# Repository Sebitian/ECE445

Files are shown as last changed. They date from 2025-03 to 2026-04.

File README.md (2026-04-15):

# Smart Bike Lock System (Secured Illini)

Embedded IoT system for real-time bike security, combining Bluetooth authentication, motion-based tamper detection, and cloud monitoring. Designed and built as a full-stack hardware + firmware solution with a custom PCB, power subsystem, and multi-state control architecture.

<p align="center">
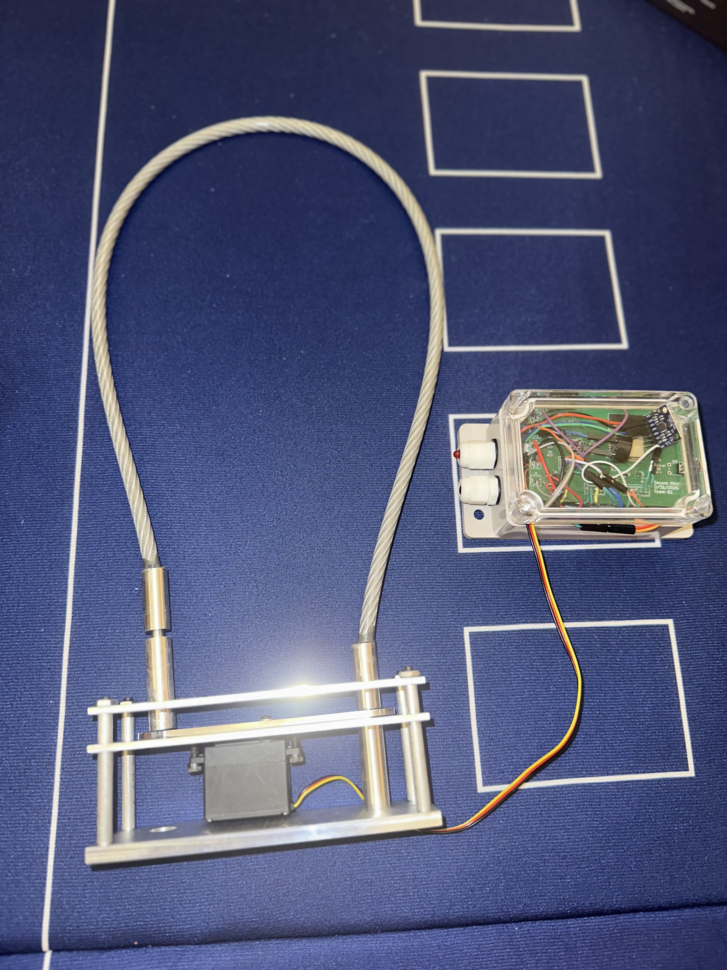
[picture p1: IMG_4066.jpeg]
Smart Bike Lock
  
</p>

---

## Overview

This project addresses the limitations of traditional bike locks by introducing a multi-layered smart security system. The device enables keyless locking via Bluetooth, detects unauthorized motion using onboard sensors, and sends real-time alerts to a cloud dashboard.

The system integrates embedded firmware, wireless communication, and physical hardware design into a single cohesive product.

---

## Key Features

- Bluetooth Low Energy (BLE) locking/unlocking
- Motion-based tamper detection using IMU (MPU6050)
- Finite State Machine (LOCKED, UNLOCKED, ALARM)
- Real-time cloud monitoring via ThingSpeak
- Servo-actuated locking mechanism
- Audible alarm + LED alert system
- Custom PCB with integrated power and control subsystems
- End-to-end system from hardware to cloud

---

## System Architecture

### Hardware
- ESP32-S3 microcontroller
- MPU6050 accelerometer/gyroscope
- Servo motor (locking mechanism)
- Piezo buzzer (alarm system)
- Custom-designed PCB
- 4.8V 2000mAh battery + 3.3V regulation (LM1117)

### Software
- Embedded C++ (Arduino framework)
- BLE server with custom services and callbacks
- HTTP-based cloud communication (ThingSpeak)
- Real-time state management using FSM

---

## Finite State Machine

The system is controlled by a 3-state FSM:

- **LOCKED**
  - Default state
  - Monitors acceleration for tampering
  - Triggers ALARM when threshold exceeded

- **UNLOCKED**
  - Triggered via authenticated BLE command
  - Disables motion-based alerts

- **ALARM**
  - Triggered on suspicious motion
  - Activates buzzer + LED flashing
  - Sends periodic cloud updates until reset

State transitions are driven by both user commands and sensor input.

---

## Motion Detection Algorithm

Tampering is detected using acceleration magnitude computed from IMU data:

- Combines x, y, z acceleration using Euclidean norm
- Adjusts for gravity (~9.8 m/s²)
- Triggers alarm when threshold exceeds ~13 m/s²

This approach enables robust detection of real-world disturbances while filtering noise.

---

## Cloud Monitoring

- Data sent via HTTP POST to ThingSpeak
- Logged data includes:
  - Lock state (LOCKED / UNLOCKED / ALARM)
  - Temperature
  - Acceleration (x, y, z)

**Performance:**
- Alert latency: ~22 seconds from tamper event to dashboard update
- Continuous updates every 15 seconds during alarm state

---

## Performance & Testing

- Lock/unlock response time: ~1.5 seconds via BLE  
- Reliable motion detection using threshold-based IMU analysis  
- Real-time alert system validated through live testing  
- Estimated battery life:
  - ~2.3 days (passive)
  - Higher under optimized conditions  

---

## Engineering Challenges

- Initial PCB revisions lacked proper USB-UART connections
- Stepper motor limitations required redesign → switched to servo
- Debugging soldering and signal integrity issues under ESP32
- BLE + WiFi integration timing and reliability

---

## Solutions

- Redesigned PCB with correct USB bridge integration
- Transitioned to servo motor for precise control
- Iterative debugging and hardware refinement
- Optimized firmware for stable communication and control

---

## Future Improvements

- Mobile application for improved user experience
- GPS tracking for stolen bike recovery
- Push notifications instead of dashboard polling
- Power optimization for extended battery life
- Modular smart attachment for existing locks

---

## Team

- Sebastian Sovailescu  
- Andrew Ruiz  
- Bowen Cui  

University of Illinois Urbana-Champaign  
ECE 445 – Senior Design

---

## Summary

This project demonstrates the design and implementation of a complete embedded system integrating hardware, firmware, and cloud infrastructure. It highlights real-world engineering challenges, iterative development, and system-level thinking in building a practical IoT security device.

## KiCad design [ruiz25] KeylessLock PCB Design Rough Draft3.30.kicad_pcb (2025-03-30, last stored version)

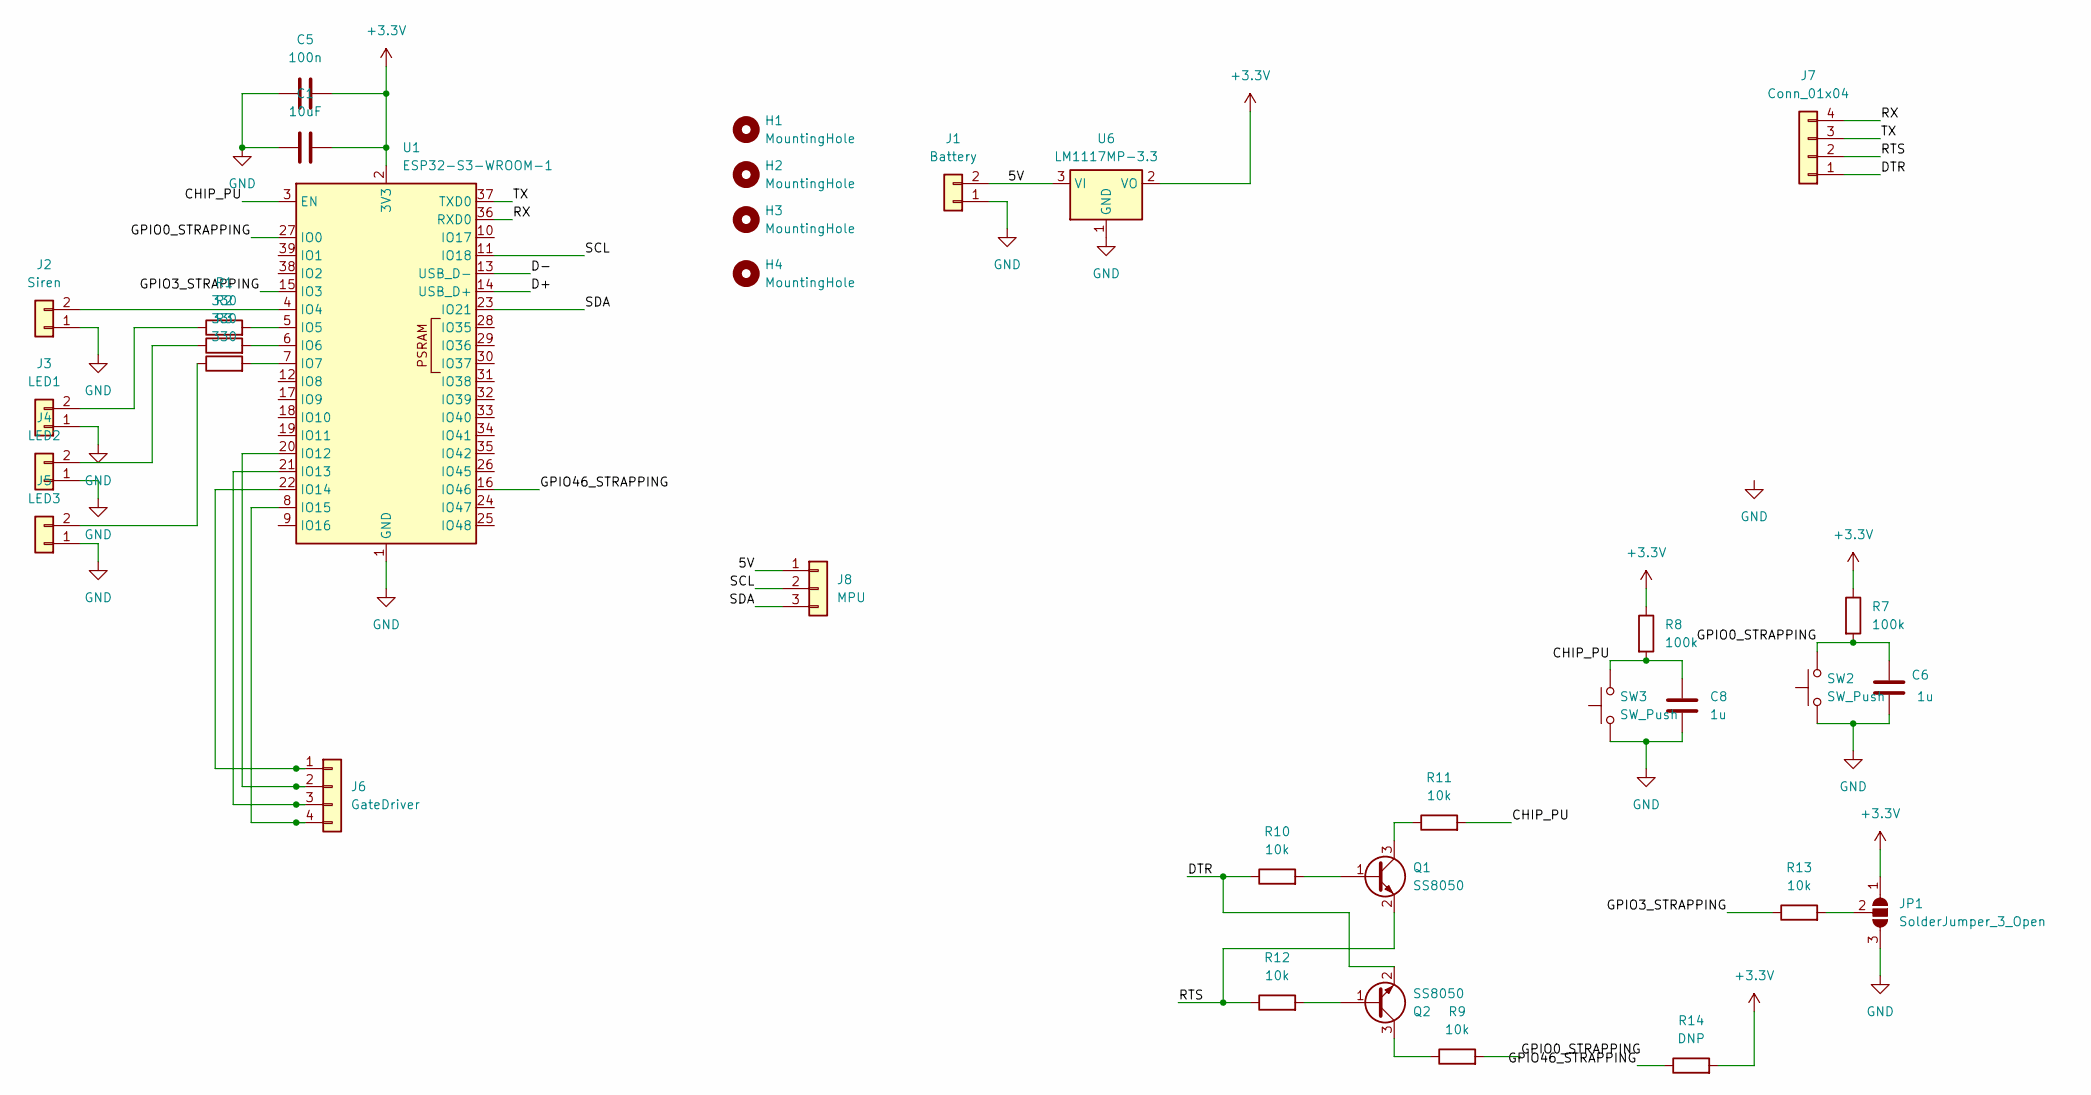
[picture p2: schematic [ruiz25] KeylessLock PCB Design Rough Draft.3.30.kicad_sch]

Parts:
C1: 10uF; C_0805_2012Metric_Pad1.18x1.45mm_HandSolder
C5: 100n; C_0805_2012Metric_Pad1.18x1.45mm_HandSolder
C6, C8: 1u; C_0805_2012Metric_Pad1.18x1.45mm_HandSolder
H1, H2, H3, H4: MountingHole; MountingHole_3.2mm_M3
J1: Battery; Molex_KK-254_AE-6410-02A_1x02_P2.54mm_Vertical
J2: Siren; Molex_KK-254_AE-6410-02A_1x02_P2.54mm_Vertical
J3: LED1; Molex_KK-254_AE-6410-02A_1x02_P2.54mm_Vertical
J4: LED2; Molex_KK-254_AE-6410-02A_1x02_P2.54mm_Vertical
J5: LED3; Molex_KK-254_AE-6410-02A_1x02_P2.54mm_Vertical
J6: GateDriver; Molex_KK-254_AE-6410-04A_1x04_P2.54mm_Vertical
J7: Conn_01x04; Molex_KK-254_AE-6410-04A_1x04_P2.54mm_Vertical
J8: MPU; Molex_KK-254_AE-6410-03A_1x03_P2.54mm_Vertical
JP1: SolderJumper_3_Open; R_0805_2012Metric_Pad1.20x1.40mm_HandSolder
Q1, Q2: SS8050; SOT-23
R1, R2, R3: 330; R_0805_2012Metric_Pad1.20x1.40mm_HandSolder
R7, R8: 100k; R_0805_2012Metric_Pad1.20x1.40mm_HandSolder
R9, R10, R11, R12, R13: 10k; R_0805_2012Metric_Pad1.20x1.40mm_HandSolder
R14: DNP; R_0805_2012Metric_Pad1.20x1.40mm_HandSolder
SW2, SW3: SW_Push; SW_PUSH_6mm
U1: ESP32-S3-WROOM-1
U6: LM1117MP-3.3; SOT-223-3_TabPin2

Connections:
+3.3V: C1.2, C5.2, JP1.1 (A), R7.1, R8.1, R14.2, U1.2 (3V3), U6.2 (VO)
/5V: J1.2, J8.1, U6.3 (VI)
/CHIP_PU: C8.1, R8.2, R11.2, SW3.2, U1.3 (EN)
/D+: U1.14 (USB_D+)
/D-: U1.13 (USB_D-)
/DTR: J7.1, Q2.2 (E), R10.1
/GPIO0_STRAPPING: C6.1, R7.2, R9.2, SW2.2, U1.27 (IO0)
/GPIO3_STRAPPING: R13.1, U1.15 (IO3)
/GPIO46_STRAPPING: R14.1, U1.16 (IO46)
/RTS: J7.2, Q1.2 (E), R12.1
/RX: J7.4, U1.36 (RXD0)
/SCL: J8.2, U1.11 (IO18)
/SDA: J8.3, U1.23 (IO21)
/TX: J7.3, U1.37 (TXD0)
GND: C1.1, C5.1, C6.2, C8.2, J1.1, J2.1, J3.1, J4.1, J5.1, JP1.3 (B), SW2.1, SW3.1, U1.1 (GND), U1.40 (GND), U1.41 (GND), U6.1 (GND)
unnamed: J2.2, U1.4 (IO4)
unnamed: J3.2, R1.1
unnamed: J4.2, R2.1
unnamed: J5.2, R3.1
unnamed: J6.1, U1.22 (IO14)
unnamed: J6.2, U1.20 (IO12)
unnamed: J6.3, U1.21 (IO13)
unnamed: J6.4, U1.8 (IO15)
unnamed: JP1.2 (C), R13.2
unnamed: Q1.1 (B), R10.2
unnamed: Q1.3 (C), R11.1
unnamed: Q2.1 (B), R12.2
unnamed: Q2.3 (C), R9.1
unnamed: R1.2, U1.5 (IO5)
unnamed: R2.2, U1.6 (IO6)
unnamed: R3.2, U1.7 (IO7)

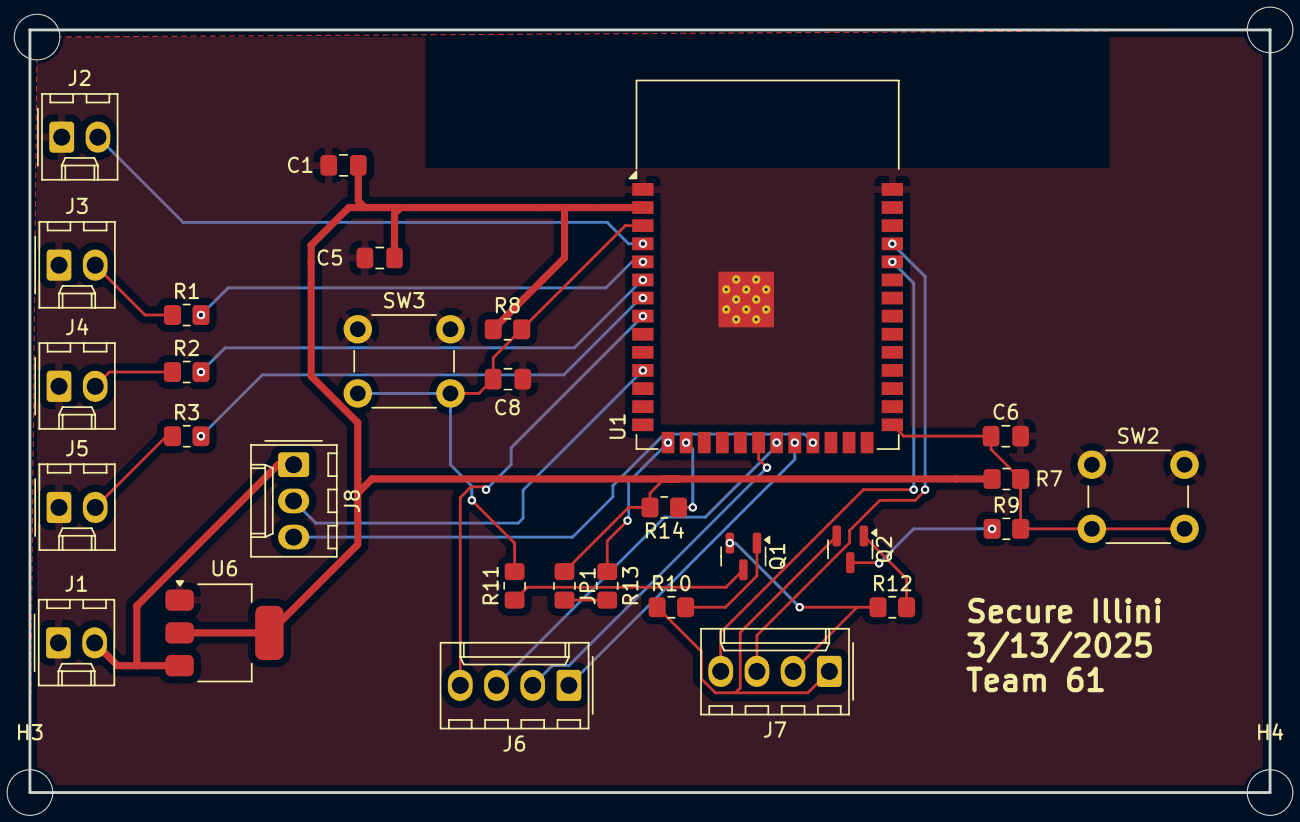
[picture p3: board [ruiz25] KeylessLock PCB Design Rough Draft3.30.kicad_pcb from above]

Board: 2 copper layers, 87.0 x 53.5 mm, 34 parts (0 on the bottom side), 29 nets.

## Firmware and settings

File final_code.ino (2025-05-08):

#include <ESP32Servo.h>
#include <Arduino.h>
#include <BLEDevice.h>
#include <BLEServer.h>
#include <BLEUtils.h>
#include <BLE2902.h>
#include <WiFi.h>
#include "ThingSpeak.h"
#include <math.h>
#include <HTTPClient.h>
#include <Adafruit_MPU6050.h>
#include <Adafruit_Sensor.h>
#include <Wire.h>
#include "pitches.h"

#define LED_PIN   7
#define SERVO_PIN 14
#define SDA_PIN     21   // your SDA pin
#define SCL_PIN     18   // your SCL pin
#define NOTE_E5  659
#define BUZZER_PIN  4

// FSM
enum LockState { LOCKED, UNLOCKED, ALARM };
LockState currentState = LOCKED;
LockState previousState = LOCKED; // Track previous state to detect changes
const float IMU_THRESHOLD = 13.0;

// MPU6050
Adafruit_MPU6050 mpu;
float temperatureC;

//==== WIFI ====
// const char* ssid       = "YOUR_SSID";       // Replace with your WiFi name
// const char* password   = "YOUR_PASSWORD";   // Replace with your WiFi password
const char* ssid       = "YOUR_WIFI_SSID";
const char* password   = "YOUR_WIFI_PASSWORD";

// === THINGSPEAK =============================================
unsigned long myChannelNumber = 1;
const char*    myWriteAPIKey  = "YOUR_THINGSPEAK_API_KEY";
const char*    serverName     = "http://api.thingspeak.com/update";

// SERVO 
Servo myservo;

// BLE ===============================================
// BLE Server callbacks (connection state)

// COMMANDS
void reset_alarm(); // type 'reset'
void play_rickroll(); // type 'rick'
void play_got_theme(); // type 'got'
void play_melody(); 
void send_to_thinkspeak();

static bool deviceConnected = false;

class ServerCallbacks : public BLEServerCallbacks {
  void onConnect(BLEServer* pServer)   override { deviceConnected = true; }
  void onDisconnect(BLEServer* pServer)override { 
    deviceConnected = false; 
    pServer->startAdvertising(); 
  }
};

// BLE Characteristic write handler
class CharCallbacks : public BLECharacteristicCallbacks {
  void onWrite(BLECharacteristic* pChar) override {
    String rx = pChar->getValue();
    if (rx.equals("open")) {
      digitalWrite(LED_PIN, HIGH);
      myservo.attach(SERVO_PIN, 1000, 2000);
      for (int pos = 0; pos <= 180; pos += 2) {
        myservo.write(pos);
        delay(15);
      }
      myservo.detach();
      
      // Change state to UNLOCKED when opening via Bluetooth
      if (currentState != UNLOCKED) {
        previousState = currentState;
        currentState = UNLOCKED;
        // Send state change to ThingSpeak
        send_to_thinkspeak();
        Serial.println("STATE: Changed to UNLOCKED");
      }
    }
    else if (rx.equals("close")) {
      digitalWrite(LED_PIN, LOW);
      myservo.attach(SERVO_PIN, 1000, 2000);
      for (int pos = 180; pos >= 0; pos -= 2) {
        myservo.write(pos);
        delay(15);
      }
      myservo.detach();
      
      // Change state to LOCKED when closing via Bluetooth
      if (currentState != LOCKED) {
        previousState = currentState;
        currentState = LOCKED;
        // Send state change to ThingSpeak
        send_to_thinkspeak();
        Serial.println("STATE: Changed to LOCKED");
      }
    }
    else if (rx.equals("reset")) {
      // Reset the alarm state via Bluetooth
      reset_alarm();
    }
    else if (rx.equals("rick")) {
      // Play the Rick Roll melody when receiving "rick" command
      Serial.println("Rick Roll activated!");
      play_rickroll();
    }
    else if (rx.equals("got")) {
      // Play the Game of Thrones theme when receiving "got" command
      Serial.println("Game of Thrones theme activated!");
      play_got_theme();
    }
  }
};


//==== BUZZER ====
int melody[]       = { NOTE_E5, NOTE_E5, NOTE_E5 };
int noteDurations[] = { 8, 8, 4 };

// WIFI
void init_WiFi() {
  WiFi.mode(WIFI_STA);
  WiFi.begin(ssid, password);
  while (WiFi.status() != WL_CONNECTED) {
    Serial.print('.');
    digitalWrite(LED_PIN, HIGH);
    delay(300);
    digitalWrite(LED_PIN, LOW);
    delay(700);
  }
  // WiFi connected - solid LED for 3 seconds
  digitalWrite(LED_PIN, HIGH);
  delay(3000);
  digitalWrite(LED_PIN, LOW);
}

// MELODY
void play_melody() {
  // Calculate the actual number of notes in the active melody
  int size = sizeof(melody) / sizeof(int);

  for (int thisNote = 0; thisNote < size; thisNote++) {
    // Calculate note duration
    int noteDuration = 1000 / noteDurations[thisNote];
    tone(BUZZER_PIN, melody[thisNote], noteDuration);

    // Pause between notes
    int pauseBetweenNotes = noteDuration * 1.30;
    delay(pauseBetweenNotes);
    
    // Stop the tone
    noTone(BUZZER_PIN);
  }
}

// LED
void init_led() {
  pinMode(LED_PIN, OUTPUT);
  digitalWrite(LED_PIN, LOW);
}

// BLE
void init_ble() {
  
  // Prepare PWM timers (don't attach yet)
  ESP32PWM::allocateTimer(0);
  ESP32PWM::allocateTimer(1);
  ESP32PWM::allocateTimer(2);
  ESP32PWM::allocateTimer(3);

  // BLE setup
  BLEDevice::init("ESP32-S3");
  BLEServer* pServer = BLEDevice::createServer();
  pServer->setCallbacks(new ServerCallbacks());

  BLEService* pService = pServer->createService("12345678-1234-1234-1234-1234567890ab");
  BLECharacteristic* pChar = pService->createCharacteristic(
    "abcdefab-1234-1234-1234-abcdefabcdef",
    BLECharacteristic::PROPERTY_READ   |
    BLECharacteristic::PROPERTY_WRITE  |
    BLECharacteristic::PROPERTY_NOTIFY
  );
  pChar->addDescriptor(new BLE2902());
  pChar->setValue("Ready");
  pChar->setCallbacks(new CharCallbacks());

  pService->start();
  BLEDevice::getAdvertising()->addServiceUUID(pService->getUUID());
  BLEDevice::getAdvertising()->start();
}


void init_MPU6050() {
  Wire.begin(SDA_PIN, SCL_PIN);
  while (!mpu.begin()) {
    Serial.println("Failed to find MPU6050 chip");
    // MPU failure pattern: very fast blinking (10 times)
    for (int i = 0; i < 10; i++) {
      digitalWrite(LED_PIN, HIGH);
      delay(50);
      digitalWrite(LED_PIN, LOW);
      delay(50);
    }
    delay(1000);
  }
  
  // MPU found - indicate with a double blink pattern
  for (int i = 0; i < 2; i++) {
    digitalWrite(LED_PIN, HIGH);
    delay(500);
    digitalWrite(LED_PIN, LOW);
    delay(500);
  }
  
  Serial.println("MPU6050 Found!");

  mpu.setAccelerometerRange(MPU6050_RANGE_8_G);
  Serial.print("Accelerometer range set to: ");
  switch (mpu.getAccelerometerRange()) {
    case MPU6050_RANGE_2_G:
      Serial.println("+-2G");
      break;
    case MPU6050_RANGE_4_G:
      Serial.println("+-4G");
      break;
    case MPU6050_RANGE_8_G:
      Serial.println("+-8G");
      break;
    case MPU6050_RANGE_16_G:
      Serial.println("+-16G");
      break;
  }
  mpu.setGyroRange(MPU6050_RANGE_500_DEG);
  Serial.print("Gyro range set to: ");
  switch (mpu.getGyroRange()) {
    case MPU6050_RANGE_250_DEG:
      Serial.println("+- 250 deg/s");
      break;
    case MPU6050_RANGE_500_DEG:
      Serial.println("+- 500 deg/s");
      break;
    case MPU6050_RANGE_1000_DEG:
      Serial.println("+- 1000 deg/s");
      break;
    case MPU6050_RANGE_2000_DEG:
      Serial.println("+- 2000 deg/s");
      break;
  }

  mpu.setFilterBandwidth(MPU6050_BAND_5_HZ);
  Serial.print("Filter bandwidth set to: ");
  switch (mpu.getFilterBandwidth()) {
    case MPU6050_BAND_260_HZ:
      Serial.println("260 Hz");
      break;
    case MPU6050_BAND_184_HZ:
      Serial.println("184 Hz");
      break;
    case MPU6050_BAND_94_HZ:
      Serial.println("94 Hz");
      break;
    case MPU6050_BAND_44_HZ:
      Serial.println("44 Hz");
      break;
    case MPU6050_BAND_21_HZ:
      Serial.println("21 Hz");
      break;
    case MPU6050_BAND_10_HZ:
      Serial.println("10 Hz");
      break;
    case MPU6050_BAND_5_HZ:
      Serial.println("5 Hz");
      break;
  }
}

// THINGSPEAK
void send_to_thinkspeak() {
  // Short blink to indicate HTTP request is starting
  digitalWrite(LED_PIN, HIGH);
  delay(200);
  digitalWrite(LED_PIN, LOW);

  WiFiClient client;
  HTTPClient http;
  http.begin(client, serverName);
  http.addHeader("Content-type", "application/x-www-form-urlencoded");
      
  // Get sensor readings
  sensors_event_t a, g, temp;
  mpu.getEvent(&a, &g, &temp);

  // Apply temperature calibration offset (MPU6050 needs calibration)
  temperatureC = temp.temperature;  // Apply offset correction
  
  // Set the status field based on the current state
  int statusValue;
  switch (currentState) {
    case LOCKED:
      statusValue = 1;  // LOCKED state = 1
      break;
    case UNLOCKED:
      statusValue = 0;  // UNLOCKED state = 0
      break;
    case ALARM:
      statusValue = 2;  // ALARM state = 2
      break;
    default:
      statusValue = 3;  // Unknown state = 3 (should never happen)
      break;
  }

  // Get acceleration data
  float accel_x = a.acceleration.x;
  float accel_y = a.acceleration.y;
  float accel_z = a.acceleration.z;

  // Blink LED once if data is read successfully
  digitalWrite(LED_PIN, HIGH);
  delay(50);
  digitalWrite(LED_PIN, LOW);

  String httpRequestData = String("api_key=") + myWriteAPIKey +
                                "&field1=" + String(temperatureC, 2) +  // 2 decimal places precision
                              "&field2=" + statusValue +              // State indicator (1=LOCKED, 0=UNLOCKED, 2=ALARM)
                              "&field3=" + String(accel_x, 3) +       // x-axis acceleration
                              "&field4=" + String(accel_y, 3) +       // y-axis acceleration
                              "&field5=" + String(accel_z, 3);        // z-axis acceleration

  int httpResponseCode = http.POST(httpRequestData);
  
  // Indicate HTTP response status through LED
  if (httpResponseCode > 0) {
    // Success - LED stays on for 1 second
    digitalWrite(LED_PIN, HIGH);
    delay(1000);
    digitalWrite(LED_PIN, LOW);
  } else {
    // Error - Blink quickly 5 times
    for (int i = 0; i < 5; i++) {
      digitalWrite(LED_PIN, HIGH);
      delay(100);
      digitalWrite(LED_PIN, LOW);
      delay(100);
    }
  }
  
  http.end();
}

void update_lock_state() {
  // Get sensor data
  sensors_event_t a, g, temp;
  mpu.getEvent(&a, &g, &temp);

  // Calculate acceleration magnitude
  float accelerationMagnitude = sqrt(a.acceleration.x * a.acceleration.x + 
                                     a.acceleration.y * a.acceleration.y + 
                                     a.acceleration.z * a.acceleration.z);
  
  // Account for gravity (approx 9.8 m/s²)
  accelerationMagnitude = abs(accelerationMagnitude - 9.8);
  
  // Save previous state before any changes
  previousState = currentState;
  
  // Check state transitions
  switch (currentState) {
    case LOCKED:
      // If in LOCKED state and acceleration exceeds threshold, trigger ALARM
      if (accelerationMagnitude > IMU_THRESHOLD) {
        currentState = ALARM;
        Serial.println("STATE: LOCKED -> ALARM (Motion detected!)");
        
        // Send alert to ThingSpeak when state changes to ALARM
        send_to_thinkspeak();
      }
      break;
      
    case UNLOCKED:
      // In UNLOCKED state, we don't trigger alarm on motion
      // But we could add other transitions here if needed
      break;
      
    case ALARM:
      // Periodic ThingSpeak updates while in ALARM state
      static unsigned long lastThingSpeakUpdate = 0;
      unsigned long now = millis();
      
      // Send update every 15 seconds while in ALARM state
      if (now - lastThingSpeakUpdate >= 15000) {
        send_to_thinkspeak();
        lastThingSpeakUpdate = now;
        Serial.println("Sending periodic alarm update to ThingSpeak");
      }
      break;
  }
  
  // Always send update to ThingSpeak if state changed
  if (currentState != previousState) {
    // Send update to ThingSpeak for any state change
    // (we already sent for LOCKED->ALARM above, but ThingSpeak has rate limits so it's okay)
    send_to_thinkspeak();
    Serial.print("STATE: Changed from ");
    Serial.print(stateToString(previousState));
    Serial.print(" to ");
    Serial.println(stateToString(currentState));
  }
}

// Helper function to convert state enum to string for debugging
String stateToString(LockState state) {
  switch (state) {
    case LOCKED: return "LOCKED";
    case UNLOCKED: return "UNLOCKED";
    case ALARM: return "ALARM";
    default: return "UNKNOWN";
  }
}

// Handle actions based on current state
void handle_state_actions() {
  static unsigned long lastToggle = 0;
  static bool ledState = false;
  static unsigned long alarmStartTime = 0;
  
  switch (currentState) {
    case LOCKED:
      // In locked state, LED stays off
      digitalWrite(LED_PIN, LOW);
      // Reset alarm variables when returning to LOCKED state
      alarmStartTime = 0; // Reset the alarm start time so it will work again when triggered
      break;
      
    case UNLOCKED:
      // In unlocked state, LED stays on
      digitalWrite(LED_PIN, HIGH);
      // Reset alarm variables
      alarmStartTime = 0;
      break;
      
    case ALARM:
      // If this is the first time in ALARM state, record the start time
      if (alarmStartTime == 0) {
        alarmStartTime = millis();
        // Initial alert: LED on and play sound immediately
        digitalWrite(LED_PIN, HIGH);
        play_melody();
        ledState = true;
        lastToggle = millis();
      }
      
      // Continue flashing LED regardless of time spent in ALARM state
      unsigned long now = millis();
      if (now - lastToggle > 500) {
        // Toggle LED state
        ledState = !ledState;
        digitalWrite(LED_PIN, ledState);
        lastToggle = now;
        
        // Only play melody when LED turns ON and within first 10 seconds
        if (ledState && (now - alarmStartTime < 10000)) {
          play_melody(); // Play sound when LED turns on
        }
      }
      break;
  }
}

// Modified function to reset the alarm state via BLE
void reset_alarm() {
  LockState oldState = currentState;
  currentState = LOCKED;
  digitalWrite(LED_PIN, LOW);
  
  // Close the servo to ensure it's in locked position
  myservo.attach(SERVO_PIN, 1000, 2000);
  for (int pos = 180; pos >= 0; pos -= 2) {
    myservo.write(pos);
    delay(15);
  }
  myservo.detach();
  
  // Always send update to ThingSpeak when resetting alarm state
  Serial.println("STATE: Reset to LOCKED from " + stateToString(oldState));
  send_to_thinkspeak();  // Ensure ThingSpeak is updated regardless of previous state
}

// Add the Rick Roll melody notes and durations
// This is a simplified version of the melody using notes from pitches.h
void play_rickroll() {
  // Notes for "Never Gonna Give You Up" intro/chorus (simplified)
  int rickNotes[] = {
    NOTE_D5, NOTE_E5, NOTE_A4, NOTE_E5, NOTE_FS5, NOTE_A5, NOTE_G5, NOTE_FS5,
    NOTE_D5, NOTE_E5, NOTE_A4, NOTE_A4, NOTE_FS5, NOTE_G5, NOTE_E5
  };
  
  // Note durations: 4 = quarter note, 8 = eighth note, etc.
  int rickDurations[] = {
    8, 8, 8, 8, 8, 8, 8, 8,
    8, 8, 4, 8, 8, 8, 4
  };
  
  // Play each note in the melody
  for (int thisNote = 0; thisNote < sizeof(rickNotes) / sizeof(int); thisNote++) {
    // Calculate note duration
    int noteDuration = 1000 / rickDurations[thisNote];
    tone(BUZZER_PIN, rickNotes[thisNote], noteDuration);
    
    // Pause between notes (30% extra seems to sound good)
    int pauseBetweenNotes = noteDuration * 1.30;
    delay(pauseBetweenNotes);
    
    // Stop the tone
    noTone(BUZZER_PIN);
  }
}

// Add Game of Thrones theme song
#define REST 0  // Add REST note definition to play pauses

void play_got_theme() {
  // Game of Thrones theme song
  int got_melody[] = {
    NOTE_G4, NOTE_C4, NOTE_DS4, NOTE_F4, NOTE_G4, NOTE_C4, NOTE_DS4, NOTE_F4,
    NOTE_G4, NOTE_C4, NOTE_DS4, NOTE_F4, NOTE_G4, NOTE_C4, NOTE_DS4, NOTE_F4,
    NOTE_G4, NOTE_C4, NOTE_E4, NOTE_F4, NOTE_G4, NOTE_C4, NOTE_E4, NOTE_F4,
    NOTE_G4, NOTE_C4, NOTE_E4, NOTE_F4, NOTE_G4, NOTE_C4, NOTE_E4, NOTE_F4,
    NOTE_G4, NOTE_C4,
    
    NOTE_DS4, NOTE_F4, NOTE_G4, NOTE_C4, NOTE_DS4, NOTE_F4,
    NOTE_D4,
    NOTE_F4, NOTE_AS3,
    NOTE_DS4, NOTE_D4, NOTE_F4, NOTE_AS3,
    NOTE_DS4, NOTE_D4, NOTE_C4,
    
    NOTE_G4, NOTE_C4,
    
    NOTE_DS4, NOTE_F4, NOTE_G4, NOTE_C4, NOTE_DS4, NOTE_F4,
    NOTE_D4,
    NOTE_F4, NOTE_AS3,
    NOTE_DS4, NOTE_D4, NOTE_F4, NOTE_AS3,
    NOTE_DS4, NOTE_D4, NOTE_C4,
    NOTE_G4, NOTE_C4,
    NOTE_DS4, NOTE_F4, NOTE_G4, NOTE_C4, NOTE_DS4, NOTE_F4,
    
    NOTE_D4,
    NOTE_F4, NOTE_AS3,
    NOTE_D4, NOTE_DS4, NOTE_D4, NOTE_AS3,
    NOTE_C4,
    NOTE_C5,
    NOTE_AS4,
    NOTE_C4,
    NOTE_G4,
    NOTE_DS4,
    NOTE_DS4, NOTE_F4,
    NOTE_G4
  };
  
  int got_durations[] = {
    8, 8, 16, 16, 8, 8, 16, 16,
    8, 8, 16, 16, 8, 8, 16, 16,
    8, 8, 16, 16, 8, 8, 16, 16,
    8, 8, 16, 16, 8, 8, 16, 16,
    4, 4,
    
    16, 16, 4, 4, 16, 16,
    1,
    4, 4,
    16, 16, 4, 4,
    16, 16, 1,
    
    4, 4,
    
    16, 16, 4, 4, 16, 16,
    1,
    4, 4,
    16, 16, 4, 4,
    16, 16, 1,
    4, 4,
    16, 16, 4, 4, 16, 16,
    
    2,
    4, 4,
    8, 8, 8, 8,
    1,
    2,
    2,
    2,
    2,
    2,
    4, 4,
    1
  };
  
  // Play the melody
  int size = sizeof(got_durations) / sizeof(int);

  for (int note = 0; note < size; note++) {
    // Calculate note duration
    int duration = 1000 / got_durations[note];
    
    if (got_melody[note] == REST) {
      // If it's a rest, just delay without tone
      delay(duration * 1.30);
    } else {
      // Play the note
      tone(BUZZER_PIN, got_melody[note], duration);
      
      // Pause between notes (30% extra seems to work well)
      int pauseBetweenNotes = duration * 1.30;
      delay(pauseBetweenNotes);
      
      // Stop the tone
      noTone(BUZZER_PIN);
    }
  }
}

// ——————————————————————————————
// Initialization
void setup() {
  Serial.begin(115200);
  init_led();
  init_WiFi();
  init_ble();
  play_melody();
  init_MPU6050();
  
  // Start in LOCKED state
  currentState = LOCKED;
  
  // Send initial state to ThingSpeak during bootup
  Serial.println("STATE: Initial LOCKED state at bootup");
  send_to_thinkspeak();
}

void loop() {
  // Update lock state based on sensor readings
  update_lock_state();
  
  // Perform actions based on current state
  handle_state_actions();
  
  // BLE handling happens in callbacks
  
  // Short delay between updates
  delay(100);
}
